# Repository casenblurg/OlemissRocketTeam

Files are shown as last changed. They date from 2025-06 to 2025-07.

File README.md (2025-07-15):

# SRM Test Stand – Casey Heustess
## Quick Results
<p align="center">
  <br/>
  <a href="https://youtu.be/v420piRjhMA" target="_blank">Youtube: Static Test Burn </a>
</p>

<p align="center">
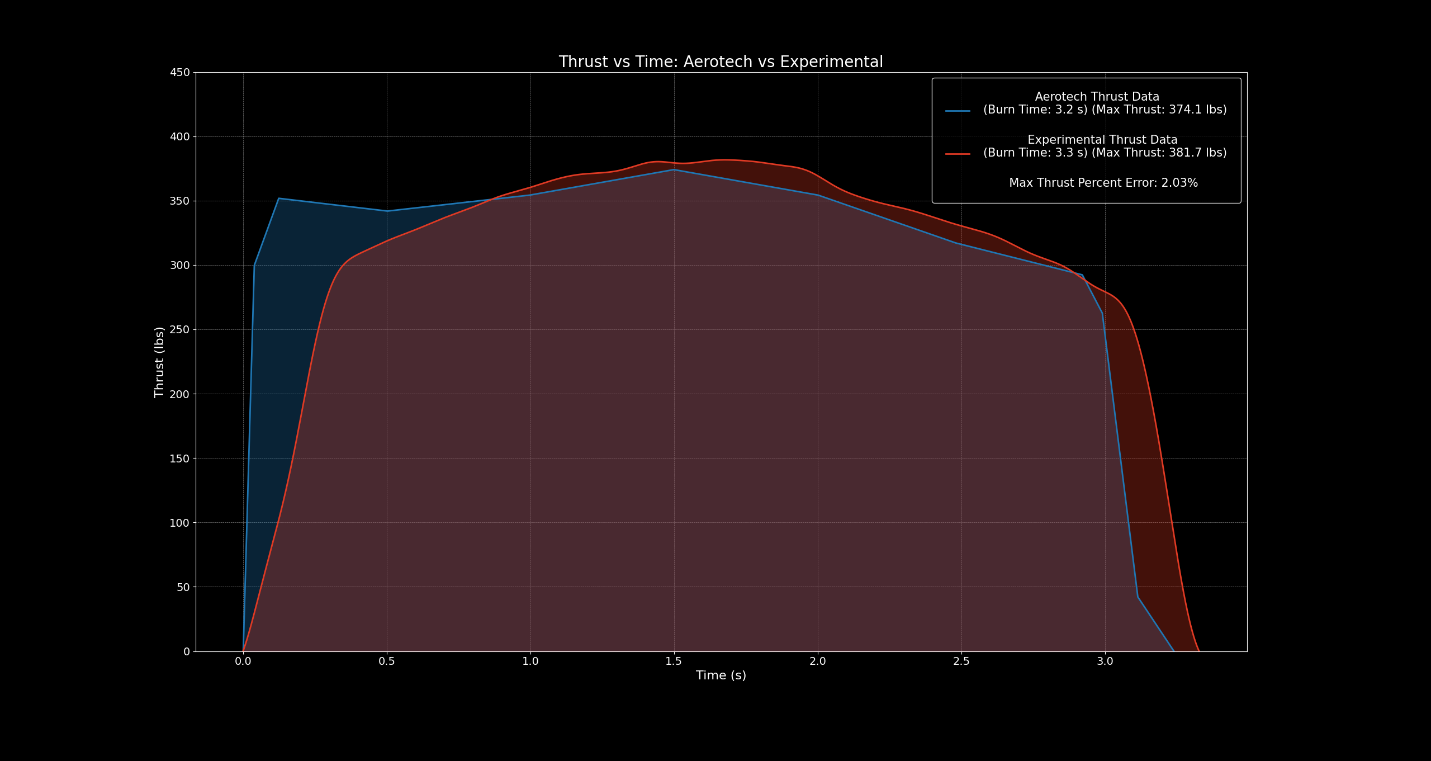
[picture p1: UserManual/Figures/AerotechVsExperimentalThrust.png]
  
</p>

<p align="center">
  <a href="https://www.thrustcurve.org/motors/AeroTech/L1420R/" target="_blank">Aerotech Thrust Data Source</a> &nbsp;|&nbsp;
  <a href="https://github.com/casenblurg/OlemissRocketTeam/blob/main/Main/BurnData/Test%20Burn%202/Force_Test2.csv" target="_blank">Raw Force Data</a>
</p>

Over the course of a year and a half (**Nov 2023 – July 2025**), I designed and built a data acquisition (DAQ) system for a **solid rocket motor (SRM) test stand**. This system was developed to accurately record **thrust** and **chamber pressure** data during static fire tests of **AeroTech reloadable SRMs**.

The DAQ setup interfaces with both an **omega load cell** and a **omega pressure transducer**, conditions their analog signals using supporting circuitry, and saves the data for post-processing and analysis.

---

## Hardware

| Component | Description |
|---|---|
| [**NI cDAQ-9174**](https://www.ni.com/docs/en-US/bundle/cdaq-9174-specs/page/specs.html) | Chassis for data acquisition modules |
| [**NI 9201**](https://www.ni.com/docs/en-US/bundle/ni-9201-specs/page/specs.html) | 12-bit analog input module (used to read sensor voltages) |
| [**NI 9482**](https://www.ni.com/docs/en-US/bundle/ni-9482-sbrio-9482-specs/resource/ni-9482-sbrio-9482-specs.pdf) | Electromechanical relay module for control logic |
| [**DR-ODC5**](https://www.sensata.com/sites/default/files/a/sensata-dr-series-output-modules-datasheet.pdf) | Solid-state relay used for ignition |
| [**PS-1S400EP**](https://www.computer-world.pro/t-win-ps-1s400ep-400w-p-97811.html) | 400 W power supply unit |
| [**Computer Supply Breakout Board**](https://www.amazon.com/GeeekPi-Breakout-Adapter-Terminal-Computer/dp/B08MC389FQ) | ATX breakout board for regulated voltage output |
| [**INA110**](https://www.ti.com/lit/ds/symlink/ina110.pdf) | Instrumentation amplifier for signal conditioning (load cell) |
| [**LC113B-2K Omega S‑type Load Cell**](https://mx.omega.com/pptst_eng/LC103B.html) | Measures thrust in lbf |
| [**PX309‑3KG10V Omega Pressure Transducer**](https://assets.omega.com/pdf/test-and-measurement-equipment/pressure/pressure-transducers/PX309.pdf) | Measures chamber pressure in psi |
| [**AeroTech RMS‑75 Combustion Chamber**](https://aerotech-rocketry.com/products/product_b2ff983a-e5fe-18d7-055b-b3266c6fedc6) | Reusable RMS‑75 motor case |
| [**AeroTech L1420R‑PS RMS‑75/5120 Reload Kit**](https://aerotech-rocketry.com/products/product_3872d294-577c-353f-9773-6594597dfda3) | Solid propellant reload kit (Redline™) |
| **1 µF Tantalum Capacitors** | Used for filtering power supply noise |
| **General wiring, connectors, and test stand** | Structural and electrical integration components |

---
## Daq Circuit Diagram

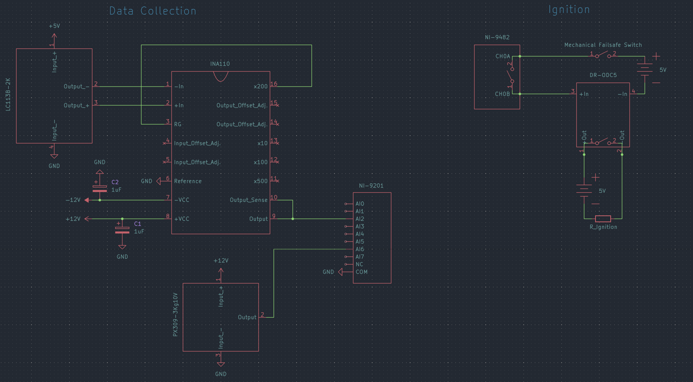
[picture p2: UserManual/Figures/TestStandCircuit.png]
Test Stand Circuit


## Daq Circuit Image
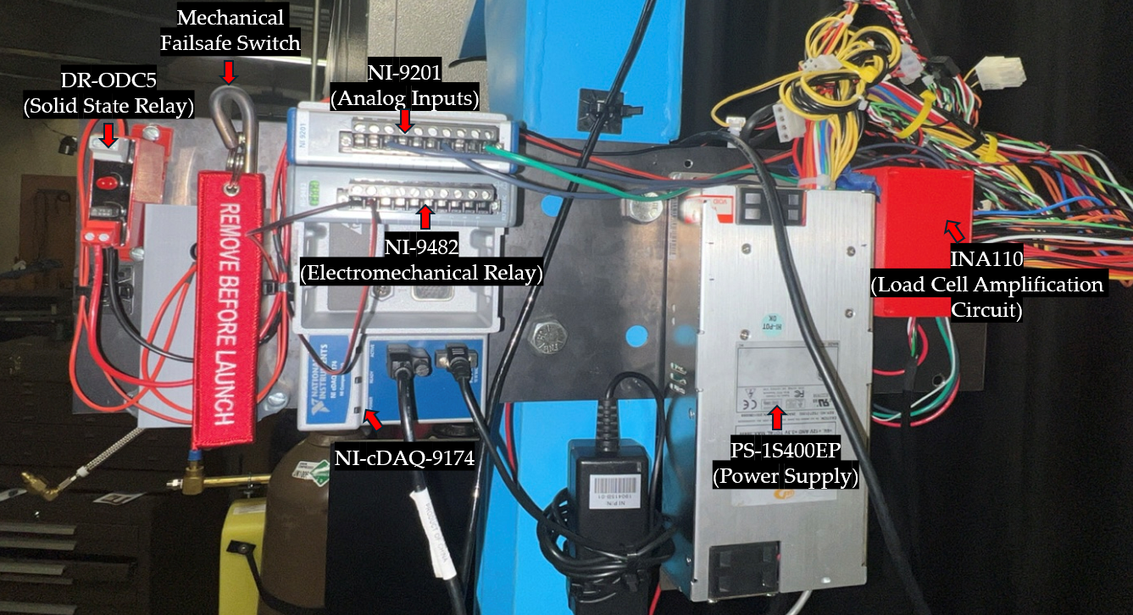
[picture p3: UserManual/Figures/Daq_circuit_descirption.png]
DAQ


---
## Software

- **NI LabVIEW**
 
<p align="center">
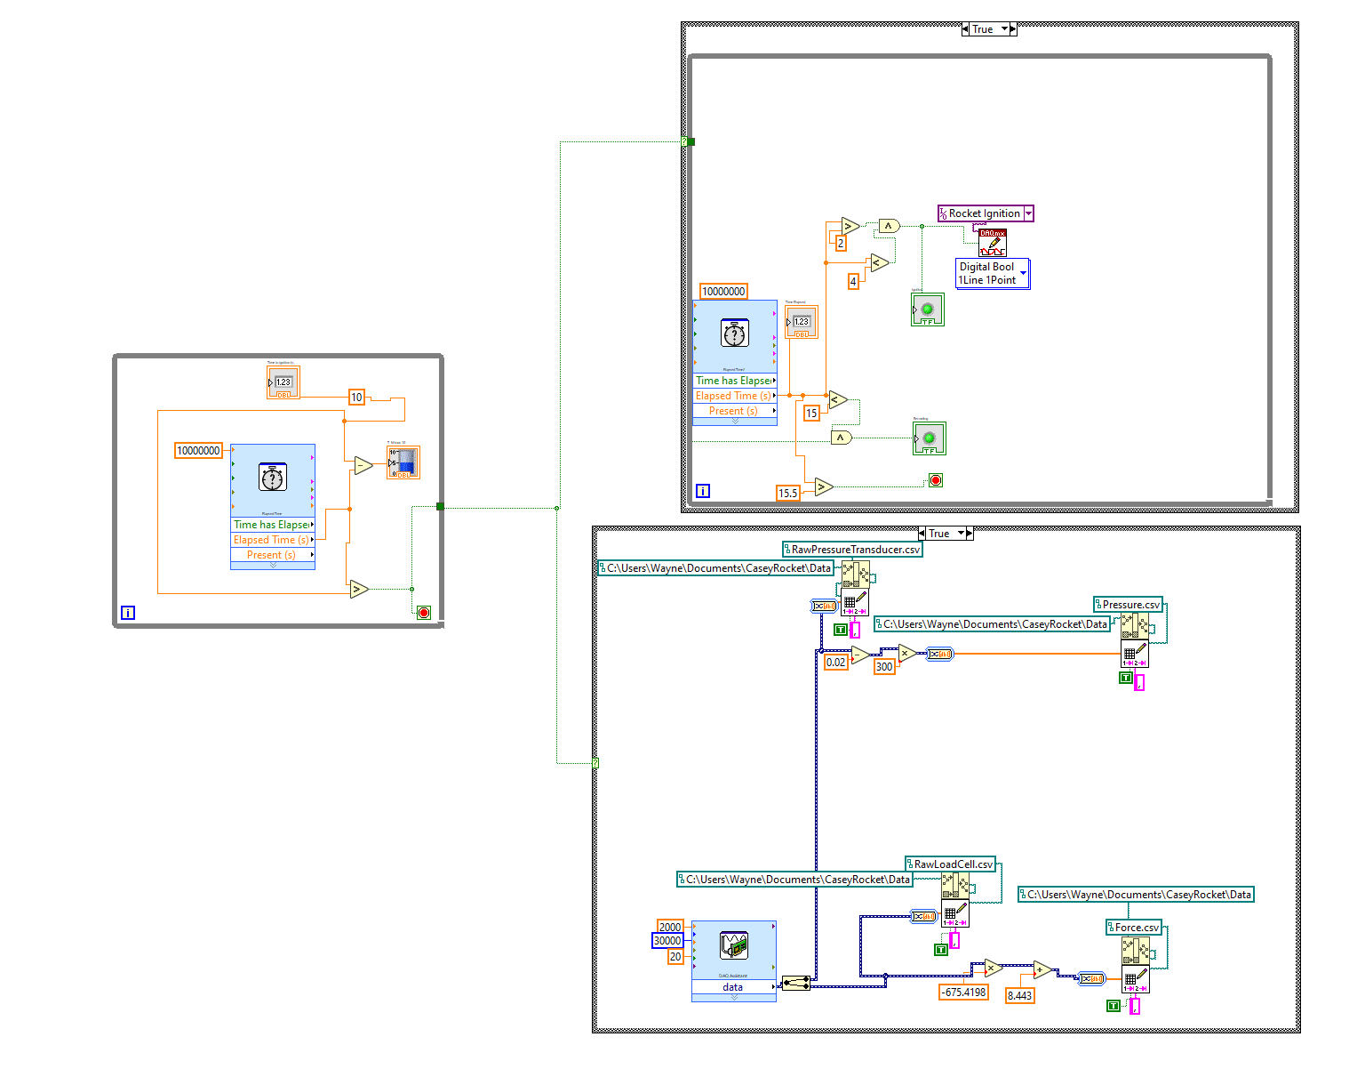
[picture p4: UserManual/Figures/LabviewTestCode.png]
  
</p>

<p align="center">
  <a href="https://github.com/casenblurg/OlemissRocketTeam/tree/main/Main/NI_LabviewCode">Labview Scripts </a>
</p>

  Used to build the real-time data acquisition interface. It handled:
  - Signal acquisition
  - Relay control for ignition
  - Timing control and logging of thrust and pressure data

- **Microsoft Excel**  
  LabVIEW exports the data into Excel spreadsheets. Each test generates:
  - Raw load cell voltage
  - Raw pressure transducer voltage
  - Converted thrust (lbf)
  - Converted chamber pressure (psi)

---

## Additional Information

The data analyzed in this repository comes from the **first hot fire test** ever recorded using this system and is used here for demonstration purposes. The goal of this repository is to showcase what can be done with acquired SRM test data. There are always better methods to explore, and continuous improvement is part of the process.

This project serves as a hands-on opportunity for me to strengthen my skills across **mechanical**, **electrical**, and **computer engineering**, as well as to sharpen my overall **data analysis abilities**, particularly in the context of **aerospace and rocketry**.

See: /Documents/SolidRocketMotor(DAQ).pdf for more info.

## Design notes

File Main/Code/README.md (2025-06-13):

# 📊 PlotData – Burn Data Visualization and Filtering

This section documents how to use the `PlotData` scripts for loading, processing, and visualizing hot fire test data from a solid rocket motor.

---

## Overview

The `PlotData.py` script is used to:
- Import raw sensor data from `.csv` files
- Show raw voltage readings from both the load cell and pressure transducer
- Apply a low-pass Butterworth filter to remove noise
- Display filtered vs. unfiltered thrust and chamber pressure data
- Relevant data is provided in this repository under: `casenblurg/OlemissRocketTeam/Data`

---

## 📁 File Structure and Function Descriptions

- **functions.py**: Contains reusable functions for filtering, plotting, and analyzing the data.
- **PlotData.py**: Imports `functions.py` and uses it to load `.csv` files and display results in grid plots.

---

## 📂 Input Files Required

To use this script, you’ll need the following files placed in a folder:
- `Force.csv`: Filtered load cell data (converted to lbf)
- `Pressure.csv`: Filtered chamber pressure (psi)
- `RawLoadCell.csv`: Raw voltage from load cell
- `RawPressureTransducer.csv`: Raw voltage from pressure transducer

---

## How to Use

1. Make sure all dependencies are installed:
```bash
pip install numpy pandas matplotlib scipy
```

2. Replace the placeholder file paths (e.g. `C:/CaseyRocket/Data/Force.csv`) in `PlotData.py` with the actual path to the CSV files on your machine. For example:
```python
pd.read_csv(r'C:/YourPath/Force.csv')
```
3. Make sure both `PlotData.py` and `functions.py` are in the same directory.

4. Run `PlotData.py`. It will:
   - Import and process the CSV data
   - Apply a filter to the data
   - Plot 4 figures: raw and filtered comparisons for force and chamber pressure

---

##  Additional Info

- Data is assumed to be sampled at **2000 Hz** for **15 seconds**, totaling **30,000 samples**.
- Filtering is done using a **4th-order low-pass Butterworth filter** with a **cutoff of 7 Hz but can be changed directly**.

---

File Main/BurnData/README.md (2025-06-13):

# 📊 Data Collection Overview

This folder contains raw and processed data collected during solid rocket motor (SRM) static fire tests. The data acquisition system was configured to sample both **chamber pressure** and **thrust** at a **rate of 2,000 Hz**, resulting in **30,000 data points** over a **15-second** burn duration.

---

##  Sampling Rate Information

###  Collection
- **Sampling Rate (fs):** 2,000 Hz  
- **Test Duration (t):** 15 seconds  
- **Total Data Points:**  
  fs × t = 2000 × 15 = **30,000 samples**

---

###  Pressure Transducer (PX309-3KGV)

- **Sample Rate:** 2,000 Hz  
- **Response Time:** ≈ 1 ms (per datasheet)  
- **Estimated Bandwidth:**  
  B ≈ 0.35 / Response Time  
  → B ≈ 0.35 / 0.001 s = **350 Hz**

- **Nyquist Criterion:**  
  fs > 2 × B  
  → 2000 Hz > 700 Hz ✅

---

###  Load Cell (LC113B-2K)

- **Sample Rate:** 2,000 Hz  
- **Estimated Response Time:** 2–5 ms (typical for S-type load cells)  
- **Estimated Bandwidth:**  
  B ≈ 0.35 / 0.002 s = **175 Hz**

- **Nyquist Criterion:**  
  fs > 2 × B  
  → 2000 Hz > 350 Hz ✅

---

## ✅ Summary

The 2,000 Hz sampling rate satisfies the Nyquist Theorem for both sensors and ensures accurate time-domain capture of fast transients in thrust and chamber pressure data. A total of **30,000 samples** per channel were collected over the 15-second window, providing high-resolution insight into motor behavior.

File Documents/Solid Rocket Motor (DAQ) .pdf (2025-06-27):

Casey Heustess 1

# Data Acquisition System Documentation

Thrust and Pressure Measurement System for Aerotech Solid Rocket Motors

## 1. System Overview

This DAQ system was developed to accurately record thrust and chamber pressure data from Aerotech solid rocket motors during static fire tests. The system captures static thrust and pressure data from both a load cell and a pressure transducer, conditions the signals, and stores the data for post-processing and analysis.

## 2. Hardware Components

The following components were used in the system:

Hardware List

- NI cDAQ-9174 – Chassis for data acquisition modules
- NI 9201 – 12-bit Analog Input Module (used to read sensor voltages)
- NI 9482 – Electromechanical Relay Module
- DR-ODC5 – Solid-state relay (used for ignition)
- PS-1S400EP – Power Supply Unit
- Computer Supply Breakout Board – Provides regulated voltage
- INA110 – Instrumentation Amplifier (for load cell signal conditioning)
- LC113B-2K Omega S-type Load Cell – Measures thrust (lbf)
- PX309-3KG10V Omega Pressure Transducer – Measures chamber pressure (psi)
- 1 µF Tantalum Capacitors – Used for filtering power supply noise
- General wiring, connectors, and test stand

## 3. Software

- NI LabVIEW – Used for real-time data acquisition, relay control, and data logging.
- Microsoft Excel and Python – Used for data filtering and post-processing.

## 4. Circuitry

Load Cell and Pressure Transducer Circuit

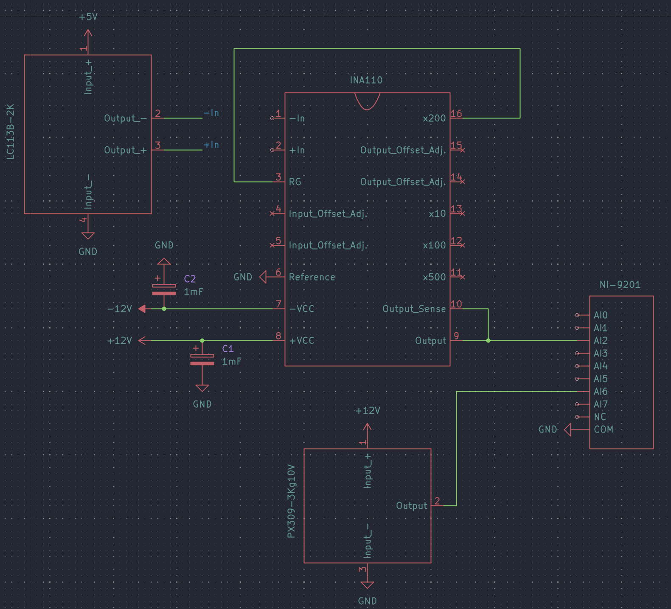
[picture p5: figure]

Ignition Circuitry

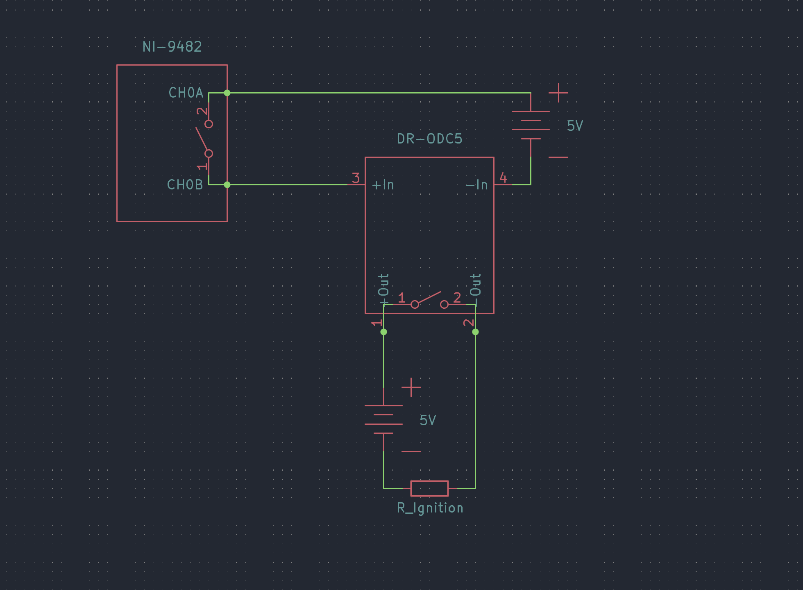
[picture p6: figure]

## 5. System Configuration

Channel Configuration

COM: Connected to common ground

AI2 (NI 9201): Amplified load cell voltage

AI6 (NI 9201): Raw pressure transducer voltage

CH0a & CH0b (NI 9482): 5V relay voltage for ignition

Sampling Rates & Rationale

- B: Bandwidth
- Fs: Sampling frequency
- N: Number of samples

Pressure Transducer (PX309-3KGV):

Sampling Rate (fs): 2000 Hz

Reason For Sample Rate: According to the transducer's datasheet, the PX309’s response time is <1 ms. A 2,000 Hz sample rate satisfies the requirement to meet the Nyquist Theorem under the assumption that the highest frequency within the data set will be less than or equal to 350 Hz.

B ≈

0.35
Response Time =

0.35
0.001 s = 350 Hz

Fs > 2B ; 2000 Hz > 700 Hz

Load Cell (LC113B-2K):

Sampling Rate (fs): 2,000 Hz

Reason For Sampling Rate:The LC113B-2K load cell datasheet does not specify an exact response time; however, based on typical performance of similar S-type load cells, the response time is estimated to be in the range of 2–5 milliseconds. A 2,000 Hz sample rate satisfies the requirement to meet the Nyquist Theorem under the assumption that the highest frequency within the data set will be less than or equal to 175 Hz.

B ≈

0.35
Response Time =

0.35
0.002 s = 175 Hz

Fs > 2B ; 2000 Hz > 350 Hz

## 6. Operation Workflow

1. System Startup:
- Power on the CDAQ and power supply
- Connect CDAQ usb to Rugged Laptop
- Open LabVIEW DAQ VI and open Main.vi
2. Data Acquisition Sequence:
- T = 0-10 s: 10-second countdown.
- T = 10 s: Data acquisition begins.
- T = 12 s: Ignition.
- T = 30 s: Data acquisition stops.
3. Data Logging:
- Four Excel files are generated after the 30-second test:
1. Pressure Voltage (Raw)
2. Pressure (PSI)
3. Load Cell Voltage (Raw)
4. Thrust (Lbf)
4. Post-Processing:
- Apply a Moving Average Filter in Excel to smooth data.
- Graph and analyze thrust and pressure profiles.

## 7. Calibration

Load Cell Calibration:

To ensure accurate thrust measurements, the load cell was calibrated using a known mass. The calibration process involved the following steps:

1. Baseline Measurement: The load cell was initialized with no applied load, and the corresponding voltage output was recorded as the zero-load reference point.
2. Known Load Application: A calibrated mass of 2Kg was carefully applied to the load cell. The voltage output corresponding to this known load was recorded.
3. Linear Calibration Curve Development: With two data points, the zero-load voltage and the 18 lbs load voltage, a linear relationship between voltage output and applied force was established. This linear equation enables the conversion of voltage readings into thrust measurements in pounds-force (lbf). The calibration equation takes the form:

Force(lb) = m * Voltage (V) + b

where m is the slope and b is the y-intercept, determined from the calibration data.

4. Implementation in LabVIEW: The derived linear equation was programmed into the LabVIEW software to allow real-time conversion of voltage readings to thrust values during data acquisition.

Pressure Transducer Calibration:

To ensure accurate pressure measurements, the PX309-3KG10V pressure transducer was calibrated against known pressure sources using the following procedure:

1. Manufacturer's Specifications:
- The PX309-3KG10V pressure transducer is rated to output 0 to 10 VDC corresponding to a pressure range of 0 to 3000 psi, when powered with an excitation voltage between 9 and 30 VDC. This results in a theoretical sensitivity of 0.00333 V/psi (3.33 mV/psi).

2. Baseline Measurement:
- The transducer output voltage was measured at 0 psi (ambient atmospheric pressure). The voltage reading was recorded as 0.019 V.
3. Known Pressure Application:
- A pressure of 100 psi was applied using the pressure lines at the National Center for Physical Acoustics (NCPA).
- The transducer output voltage at this pressure was measured to be 0.360 V.
4. Sensitivity Calculation:
- Based on the measured voltage readings, the sensitivity was determined using the following formula: Sensitivity = (0.360 V - 0.019) / 100 psi = 3.41 mV/psi.
- This measured sensitivity closely matches the theoretical value specified by the manufacturer, validating the sensor’s performance.
5. Linear Conversion Equation:
- A linear equation was established to convert voltage readings to pressure values in psi: Pressure (psi) = (Measured (V) - 0.019 V) / (0.00341 V/psi)
6. Implementation in LabVIEW:
- This conversion equation was implemented in the LabVIEW data acquisition system, allowing for real-time conversion of voltage measurements to pressure readings during motor tests.

By performing this calibration, the accuracy and reliability of the pressure measurements were validated for the specific DAQ setup and test conditions.

## 8. Safety

- Always verify the relay function prior to the test.
- Keep safe distance during ignition.
- Never Load the motor or igniter with the power supply on.
- Ensure mechanical fail-safe pin is inserted

DAQ System Setup

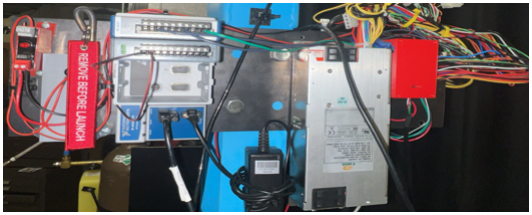
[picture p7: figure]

Resources

### 1. Omega Engineering. (n.d.). LC103B series—High accuracy, stainless steel, S-beam load

cells. Omega. https://mx.omega.com/pptst_eng/LC103B.html

### 2. Omega Engineering. (n.d.). PX309 series—General purpose, stainless steel pressure

transducers (Data sheet). Omega. https://assets.omega.com/pdf/test-and-measurement-equipment/pressure/pressure-transducers/PX309.pdf (https://assets.omega.com/pdf/test-and-measurement-equipment/pressure/pressure-transducers/PX309.pdf)

3. National Instruments. (n.d.). NI cDAQ-9174 chassis specifications. NI. https://www.ni.com/docs/en-US/bundle/cdaq-9174-specs/page/specs.html
4. National Instruments. (n.d.). NI 9201 analog input module specifications. NI. https://www.ni.com/docs/en-US/bundle/ni-9201-specs/page/specs.html
5. National Instruments. (n.d.). NI 9482 electromechanical relay module specifications. NI. https://www.ni.com/docs/en-US/bundle/ni-9482-sbrio-9482-specs/resource/ni-9482-sbrio-9482-s pecs.pdf (https://www.ni.com/docs/en-US/bundle/ni-9482-sbrio-9482-specs/resource/ni-9482-sbrio-9482-specs.pdf)
6. Sensata Technologies. (n.d.). DR series output modules datasheet. Sensata. https://www.sensata.com/sites/default/files/a/sensata-dr-series-output-modules-datasheet.pdf
7. Texas Instruments. (n.d.). INA110 precision instrumentation amplifier datasheet. TI. https://www.ti.com/lit/ds/symlink/ina110.pdf
8. T-Win. (n.d.). PS-1S400EP 400W power supply specifications. Computer World Pro. https://www.computer-world.pro/t-win-ps-1s400ep-400w-p-97811.html
9. GeeekPi. (n.d.). ATX breakout adapter terminal block power board. Amazon. https://www.amazon.com/GeeekPi-Breakout-Adapter-Terminal-Computer/dp/B08MC389FQ

## Test Plan & Checklist (Day of Burn)

Pre-Test:

- Confirm all cables and power supply are secured
- Confirm analog inputs and common are secure and connected
- Tighten all fasteners
- Ensure load cell is fastened and secure
- Plug in DAQ and Power supply
- Connect usb from DAQ to computer
- Ensure both channels are at desired sample rate and sample number
- Open Main.vi and confirm code runs correctly and saves data to excel
- CONFIRM THAT RELAY MODULE IS OFF AFTER TEST
- Check each data file for expected values at zero psi and lbs
- CLOSE ALL EXCEL FILES

Test:

- Ensure fail-safe pin is inserted
- Strap down and secure test stand
- Grease pressure transducer and fasten to threaded rod
- Load motors in combustion chamber and mount to threaded rod
- Apply the combustion chamber brackets
- Connect ignitor fuse to ignition terminals
- Insert igniter into loaded combustion chamber securely
- Confirm test site is clear
- Run Main.vi

Post-Test:

- Confirm data collection
- Clean Up test site and combustion chamber the day after
- Filter and graph data

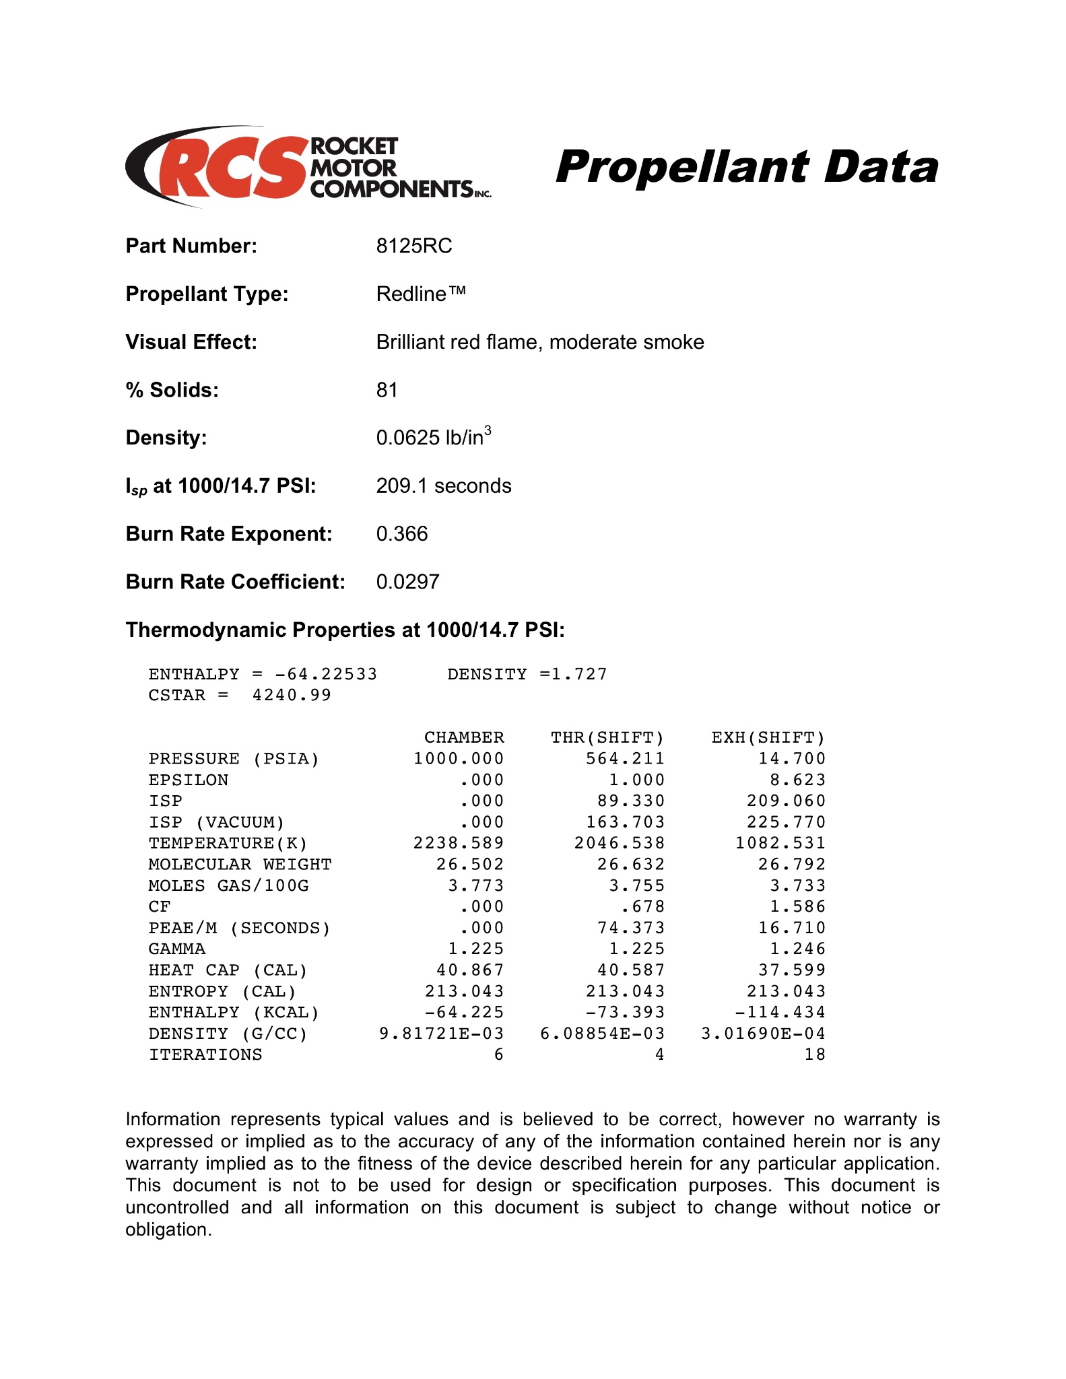
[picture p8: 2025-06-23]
Documents/Redline75mmDataSheet.jpg

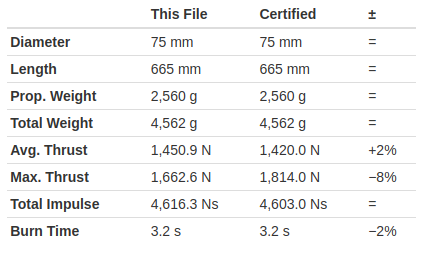
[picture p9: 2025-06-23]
Documents/TabulatedRedlineData.png

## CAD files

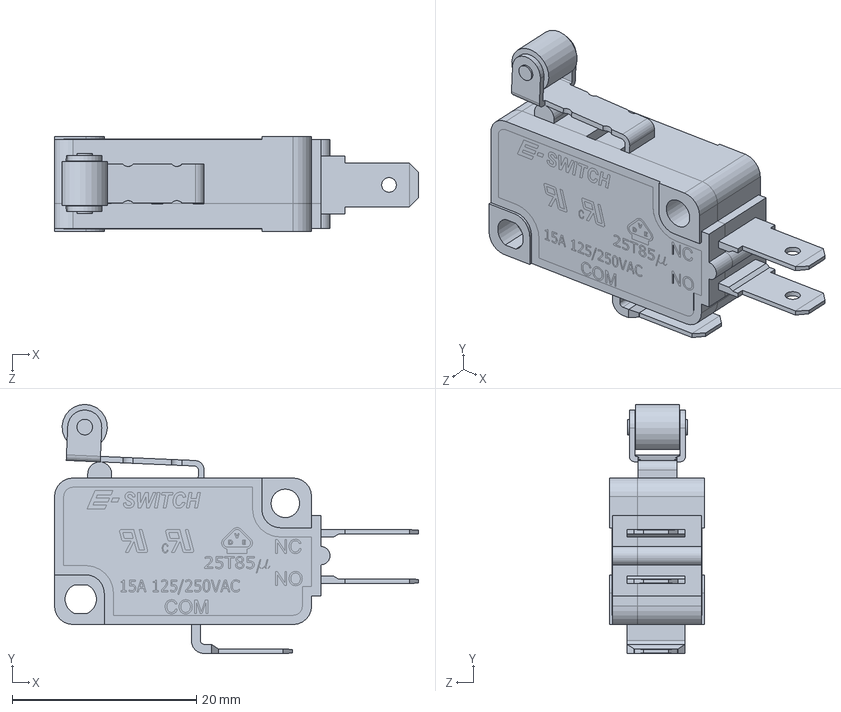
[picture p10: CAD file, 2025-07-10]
Documents/CAD/Mechanical Failsafe/LS085xx05FxxxC1A.SLDPRT
39.5 x 27.0 x 10.3 mm

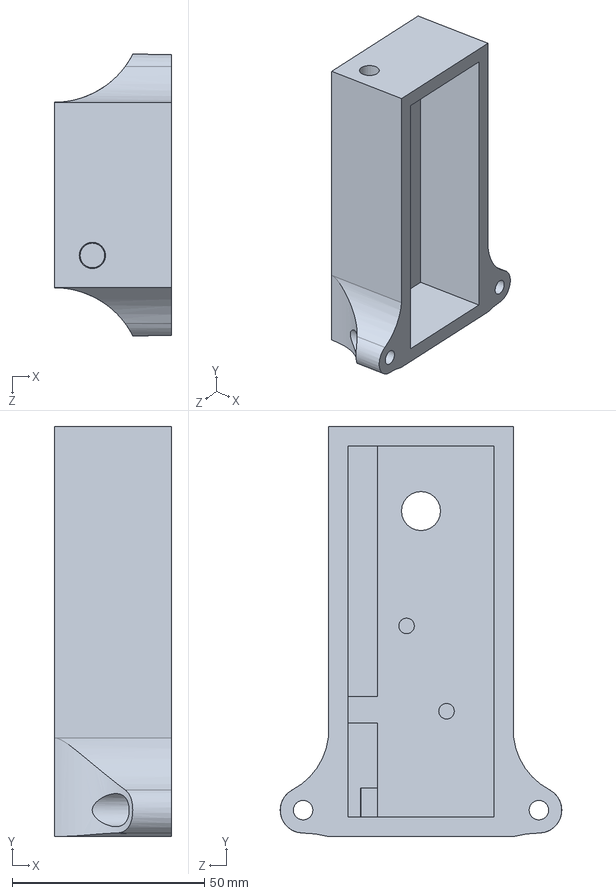
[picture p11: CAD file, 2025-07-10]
Documents/CAD/Mechanical Failsafe/MechanicalFailSafeMount.SLDPRT
30.5 x 106.7 x 73.3 mm

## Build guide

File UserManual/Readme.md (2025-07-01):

# SRM Test Stand User Manual 

## Contents

- Overview [x] 

- Hardware 
	- Omega [x]
		- Omega Load Cell (LC113B) [x]
		- Omega Pressure Transducer (PX309) [x]
	- National Instruments
		- DAQ (NI 9174) [x]
		- Analog Input Module (NI 9201) [x]
		- Electromechanical Relay (NI 9482)
	- Aerotech
		- Combustion Chamber
		- Reload Kit / Propellant

- Circuitry
	- Components
	- Design

- Software
	- NI LabView
	- Python
	- Excel
	- SolidWorks

- Sensor Calibration
	- Load Cell
	- Pressure Transducer

- SRM Testing
	- Safety
	- Test Burns
		- Pre-Test 
		- Test Day 
		- Post Test 

---
# Overview

The **SRM** (solid rocket motor) **test stand** was fabricated to aid in the testing and data collection of solid rocket motors during static burns. The test stand is capable of collecting combustion **chamber pressure** and rocket motor **thrust**. The project was **funded by the University of Mississippi** for the **Olemiss Rocket Team**. 

---
# Hardware

## Omega

There are two **Omega** sensors on the stand:

1. Omega Load Cell (LC113B)
2. Omega Pressure Transducer (PX309)

---
### Load Cell (LC113B)

[How do load cells work?](https://www.futek.com/how-a-load-cell-works?srsltid=AfmBOoodpjuVTFlQnRJYCVh5oO8KQaShKoqdbEF299_-5rnqHvmavmP9):

The load cell **converts an applied force into an output voltage** that we can measure. In this case the **[LCB113B-2K](https://www.dwyeromega.com/en-us/high-accuracy-stainless-steel-s-beam-load-cells/LC103B/p/LC113B-2K)** S-type load cell is used. This load cell is capable of withstanding **2000 lbs** of tension or compression. 

### Omega S-type load cell:

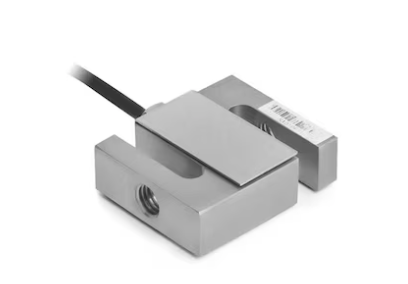
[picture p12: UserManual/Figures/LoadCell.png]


---
## Pressure Transducer (PX309)
[How do pressure transducers work?](https://www.youtube.com/watch?v=UZLiLRlJzbU)

The pressure transducer **converts an applied pressure into an output voltage** that we can measure. In this case the **[PX309-3Kg10V](https://assets.omega.com/pdf/test-and-measurement-equipment/pressure/pressure-transducers/PX309.pdf)** pressure transducer is used. Again, this product contains a data sheet that provides all necessary information on the sensor.

### Omega Pressure Transducer:

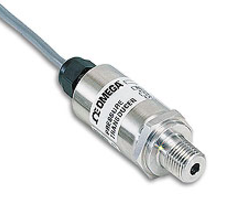
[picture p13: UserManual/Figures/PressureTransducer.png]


---

**How do we know what voltage corresponds to what force?:**

Every sensor has what is called a **[data sheet](https://assets.dwyeromega.com/spec/LC103B_spec.pdf)**, this is a **technical document provided by the manufacturer** that describes everything you need to know about a sensor — how it works, how to wire it, its limits, and how to interpret its output. Additionally, every sensor has an output sensitivity. **Output sensitivity** tells you **how much signal** a sensor gives **per supplied voltage**, usually in **millivolts per volt (mV/V)**. This will be further explained in the **sensor calibration** section.

---

# National Instruments

There are three **National Instruments** hardware components on the test stand:
1. NI cDAQ-9174
2. NI 9201 
3. NI 9482

---

## NI cDAQ-9174:

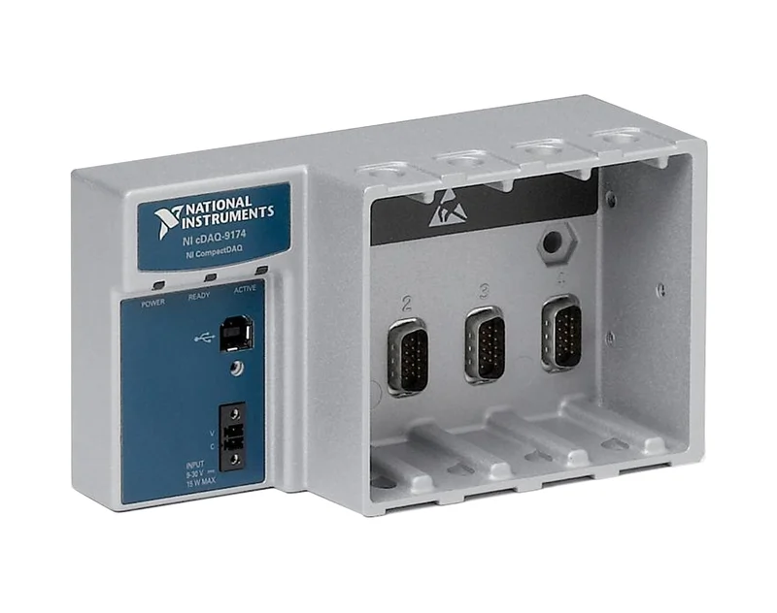
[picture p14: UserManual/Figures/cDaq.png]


The NI cDAQ-9174 stands for **National Instruments Compact DAQ**. You can plug this into your computer using **USB** and run your Labview code. You can do all sorts of things depending on what module / card you have. In this case we have an analog input card and a relay card inserted into the cDAQ. 

## Analog Input Module (NI 9201):
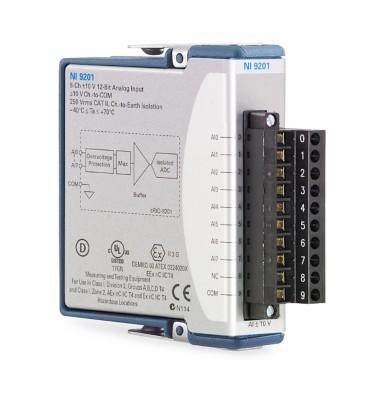
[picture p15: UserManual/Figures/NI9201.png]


This is a module that you plug in to the cDAQ, I like to think of it as a fancy multi meter. There are two main terminals to pay attention to, **COM** and **AI (analog in)**. If you were using this card as a multimeter, **COM** would go to your reference (**GND**) and **AI** would go to the voltage source you aretrying to read.

## Electromechanical Relay (NI 9482):

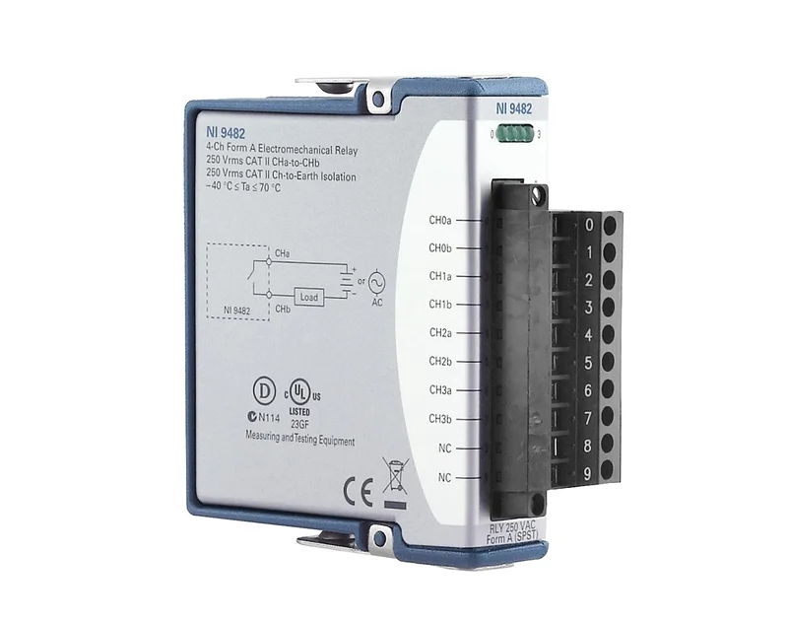
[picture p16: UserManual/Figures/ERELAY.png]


This is another module that goes into the cDAQ. It is essentially a switch that can be programmed to turn on or off using Labview. This switch is used to ignite the rocket motor during test burns.

--- 

# Aerotech

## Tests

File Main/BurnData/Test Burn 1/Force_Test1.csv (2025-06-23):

Force_lbf
-22.626617272078896
-22.626617272078896
-19.249518163360932
-19.249518163360932
-19.249518163360932
-22.626617272078896
-22.626617272078896
-19.249518163360932
-22.626617272078896
-19.249518163360932
-22.626617272078896
-22.626617272078896
-26.003716380796863
-19.249518163360932
-22.626617272078896
-15.872419054642965
-22.626617272078896
-22.626617272078896
-19.249518163360932
-19.249518163360932
-19.249518163360932
-19.249518163360932
-19.249518163360932
-19.249518163360932
-22.626617272078896
-22.626617272078896
-22.626617272078896
-15.872419054642965
-26.003716380796863
-19.249518163360932
-19.249518163360932
-22.626617272078896
-22.626617272078896
-19.249518163360932
-19.249518163360932
-22.626617272078896
-22.626617272078896
-19.249518163360932
-22.626617272078896
-22.626617272078896
-22.626617272078896
-19.249518163360932
-22.626617272078896
-19.249518163360932
-26.003716380796863
-26.003716380796863
-22.626617272078896
-19.249518163360932
-26.003716380796863
-19.249518163360932
-22.626617272078896
-19.249518163360932
-22.626617272078896
-19.249518163360932
-22.626617272078896
-22.626617272078896
-22.626617272078896
-15.872419054642965
-22.626617272078896
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

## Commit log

2025-06-23 Update, Pressure transducer might be broken
2025-06-27 Update PressureCalibration w better data
    [PressureTransducerCalibraion_goodData.csv]
2025-07-09 New Burn Data
    [Force.csv, Pressure.csv, RawLoadCell.csv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]
